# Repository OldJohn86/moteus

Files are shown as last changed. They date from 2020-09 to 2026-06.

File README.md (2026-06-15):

# moteus brushless servo #

This contains full designs for the moteus brushless servo actuator,
including firmware and PCBs.

**WARNING**: This is not just a software project.  It includes designs
for moderately high power electronics.  It has not yet burned down my
(or anyone's that I know of) house, but there are no guarantees.

# Specifications #

| Name | r4.11 | c1 | n1 | x1 |
|---|---|---|---|---|
| Voltage Input | 10-44V | 10-51V | 10-54V | 10-54V |
| Peak Electrical Power  | 900W @ 30V | 250W @ 28V | 2kW @ 36V | 1.3kW @ 36V |
| Mass | 14.2g | 8.9g | 14.6g | 23.8g |
| Control Rate | 15-30kHz | - | - | - |
| PWM Switching Rate | 15-60kHz | - | - | - |
| CPU | STM32G4 | - | - | - |
| Uncooled phase current | 12A | 5A | 9A | 25A |
| Cooled phase current | 32A | 14A | 26A | 62A |
| Peak phase current | 100A | 20A | 100A | 120A |
| Communications | 5Mbps CAN-FD | - | - | - |
| Dimensions | 46x53mm | 38x38x9mm  | 46x46x8mm | 56x56x10mm  |

Assembled and tested boards can be purchased at: https://mjbots.com

# Directory structure #

* hw/ - hardware (mechanical and electrical designs)
  * controller/ - PCB design for moteus-r4.11
  * c1/ - PCB design for moteus-c1
  * n1/ - PCB design for moteus-n1
  * x1/ - PCB design for moteus-x1
* fw/ - firmware for brushless controller
* lib/ - client side software
* utils/ - diagnostic tools
* tools/ - bazel build configure
* docs/ - documentation

# Documentation #

* [Quick Start](https://mjbots.github.io/moteus/quick-start)
* [All Documentation](https://mjbots.github.io/moteus/)
* [Discord](https://discord.gg/W4hUpBb)

# Misc #

 * 

# How to support moteus development #

The easiest way to support development the moteus hardware and firmware is as follows:

1) Buy things from https://mjbots.com
2) Build awesome machines!

That's it!  If for some reason you want to go above and beyond, you can sponsor mjbots through github: https://github.com/sponsors/mjbots

# License #

All files contained in this repository, unless otherwise noted, are
available under an Apache 2.0 License:
https://www.apache.org/licenses/LICENSE-2.0

# Trademark #

mjbots Robotic Systems LLC owns and protects the "mjbots" and "moteus" trademarks in many jurisdictions.

If you want to use these names in your project or product, please read the [Trademark Policy](https://mjbots.com/trademark-policy)

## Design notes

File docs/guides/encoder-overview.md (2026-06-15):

# Encoder Overview

This section describes the various ways moteus can be configured to use encoders to sense the rotor, output, or auxiliary devices.  If you intend to only use the onboard on-axis magnetic encoder, you can skip this section.

## Introduction

moteus uses encoders to properly control a motor. Encoders provide the feedback needed to know where the motor is and how fast it's moving. Understanding which encoder(s) to use and how to configure them is one of the key decisions you need to make when designing a system, as for many applications encoder selection is the primary determinant of performance parameters like maximum stiffness, control stability and whether homing will be necessary.

Moteus uses encoders for two distinct purposes. First, it needs **commutation** feedback - the electrical relationship between the motor's stator and rotor to apply torque correctly. Second, it needs **output** feedback - the position and velocity of your output shaft to follow commanded trajectories. A single encoder can serve both purposes, or you can use separate encoders for each.

The good news is that moteus comes with an onboard AS5047P or MA600 magnetic encoder that works out of the box for many applications. This encoder mounts on-axis with the motor. For many use cases, especially those without gear reductions, this is all you need. However, if you're using hall sensors, need higher resolution, or have a gear reducer that you want to measure the output of a reducer or other auxiliary devices, you'll want to add other encoders.

In this guide, we'll cover a few common variants and leave the rest for [the detailed encoder reference](../reference/encoders.md).

## Common Configurations

Here are the most common encoder configurations you'll encounter:

**Default configuration (onboard encoder only):** The AS5047P or MA600 onboard encoder serves as both commutation and output sensor. This works well for many applications, especially those without a reducer installed or with a reducer where either the absolute position of the output is not required or a homing step is permitted.

**Adding hall sensors:** Hall effect sensors provide robust commutation feedback and are useful in high-vibration environments or when cost is a primary concern.  When used as the only encoder, the resulting system will have poor low-velocity and position tracking performance.

**Dual encoder setups:** Using one encoder for commutation (typically the onboard or hall sensors) and a separate high-resolution encoder for output position provides the best performance for precision applications.

These two options are described in separate guides below:

- [Motor with Hall Effects](hall-effects.md) - Adding hall sensors for commutation
- [Dual Encoders](dual-encoders.md) - Using separate encoders for commutation and output

Once again, for detailed information about encoder configuration parameters, see the [Detailed Encoder Reference](../reference/encoders.md).

## Next Steps

Once the encoder has been configured, then you are ready to move on to the [motor calibration procedure](calibration.md).

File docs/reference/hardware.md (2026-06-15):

# Hardware Specifications

## CAD and Models

| Name | 2D CAD | 3D Model |
|---|---|---|
| moteus-c1 |[2D CAD](https://github.com/mjbots/moteus/blob/0.1-20240430/hw/c1/r1.2/20240305-moteus-c1-r1_2.pdf) | [STEP](https://github.com/mjbots/moteus/blob/0.1-20240430/hw/c1/r1.2/20240305-moteus-c1-r1_2.step) |
| moteus-r4 |[2D CAD](https://github.com/mjbots/moteus/blob/main/hw/controller/r4.5/20210124-moteus-controller-r45-mechanical.pdf) | [STEP](https://github.com/mjbots/moteus/blob/main/hw/controller/r4.5/20210124-moteus-controller-r45-mechanical.step) |
| moteus-x1 | [2D CAD](https://drive.google.com/file/d/1R7wuc7vk1khD5ZvDWPy54Bx4PgHYiUCu/view) | [STEP](https://drive.google.com/file/d/19tJa4gzy0ZBWYYsaJA-Du0PgzoDWizjL/view?usp=sharing) |
| moteus-n1 | [2D CAD](https://drive.google.com/file/d/1Ic65vT8BSeTtqz6uqd8C7l68aOMy3bMz/view?usp=share_link) | [STEP](https://drive.google.com/file/d/1wxX5G6kX6M6YZGGSceiXTOUZycxRaSIE/view?usp=share_link) |

## Electrical Limits

| Name | Min Voltage | Nominal | Abs Max Voltage | Peak Output | 3V Aux |  5V Aux | 12V Aux |
|---|---|---|---|---|---|---|---|
| moteus-c1 | 10V | 24V | 51V (<= 12S) | 20A | 50mA | 100mA | N/A |
| moteus-r4 | 10V | 24V | 44V (<= 10S) | 100A | 100mA | N/A | N/A |
| moteus-x1 | 10V | 24V | 54V (<= 12S) | 120A | 100mA | 200mA | 150mA |
| moteus-n1 | 10V | 24V | 54V (<= 12S) | 100A | 100mA | 200mA | N/A |

## Power Limits

The allowable maximum power for each moteus controller depends upon
the input voltage and PWM switching frequency.  The below table gives
the maximum allowable power at `servo.pwm_rate_hz=30000`.

| Name | Peak power | | High input power |
|---|---|---|---|
| moteus-r4  | <= 30V 900W  | linear derated | >= 38V 400W |
| moteus-c1  | <= 28V 250W  | linear derated | >= 41V 150W |
| moteus-n1  | <= 36V 2000W | linear derated | >= 44V 1000W |

For other values of `servo.pwm_rate_hz`, the allowable maximum power
changes linearly with the PWM rate, so that at 15000, the maximum
power is half of that in the above table and at 60000 it is double
that.  Note however, that efficiency of the controller goes down
significantly at higher PWM rates.

The current power limit is reported in `servo_stats.max_power_W`.  The
controller will attempt to limit output phase current so as to stay
within this reported power limit in either direction, i.e. applying
power or regenerating energy.

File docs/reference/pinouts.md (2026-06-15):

# Pinouts

## moteus-c1



## moteus-r4



## moteus-x1



## moteus-n1



## Additional Information

### CAN Termination

CAN connections should be terminated by a 120 ohm resistor at both
ends of a bus.  Some mjbots products have built in termination
resistors, such as the pi3hat.  The mjcanfd-usb-1x and fdcanusb have a
software configurable termination resistor that is by default on.
moteus controllers have no termination resistors.  For very short
runs, the system will work terminated only on one side.  However, when
runs become longer than 0.5m, you will likely need to terminate both
ends.  This can be done by crimping a 120 ohm resistor into a JST PH3
connector and connecting it to the open data connector or by
purchasing a [CAN terminator](https://mjbots.com/products/jst-ph3-can-fd-terminator).

### Recommended Mating Hardware

| Connector | Mate P/N | Terminal P/N | Pre-crimped Wire |
|---|---|---|---|
| JST PH-3  | [PHR-3](https://mjbots.com/products/phr-3)  | [SPH-002T-P0.5L](https://mjbots.com/products/jst-ph-terminal) | [10cm, 30cm, 50cm PH3](https://mjbots.com/products/jst-ph3-cable) |
| JST GH-6  | [GHR-06V-S](https://mjbots.com/products/jst-gh6-housing) | [SSHL-002T-P0.2](https://www.digikey.com/en/products/detail/jst-sales-america-inc/SSHL-002T-P0-2/807828) | [28 AWG 20cm](https://mjbots.com/products/jst-gh-wire) |
| JST GH-7  | [GHR-07V-S](https://mjbots.com/products/jst-gh7-housing) | [SSHL-002T-P0.2](https://www.digikey.com/en/products/detail/jst-sales-america-inc/SSHL-002T-P0-2/807828) | [28 AWG 20cm](https://mjbots.com/products/jst-gh-wire) |
| JST GH-8  | [GHR-08V-S](https://mjbots.com/products/jst-gh8-housing) | [SSHL-002T-P0.2](https://www.digikey.com/en/products/detail/jst-sales-america-inc/SSHL-002T-P0-2/807828) | [28 AWG 20cm](https://mjbots.com/products/jst-gh-wire) |
| JST ZH-4  | [ZHR-4](https://www.digikey.com/en/products/detail/jst-sales-america-inc/ZHR-4/608643) | [SZH-002T-P0.5](https://www.digikey.com/en/products/detail/jst-sales-america-inc/SZH-002T-P0-5/527363) | |
| JST ZH-6  | [ZHR-6](https://www.digikey.com/en/products/detail/jst-sales-america-inc/ZHR-6/527361) | [SZH-002T-P0.5](https://www.digikey.com/en/products/detail/jst-sales-america-inc/SZH-002T-P0-5/527363) | [stm32 programmer](https://mjbots.com/products/stm32-programmer) |
| AMass XT30 | [XT30U-F](https://mjbots.com/products/xt30u-f) | | |

### Recommended Low Cost Manual Crimp Tools

- **JST PH**: [TU-190-08](https://www.amazon.com/TU-190-08-Terminals-Tool-Crimping-0-08-0-5sq-mm/dp/B01M25OLZY)
- **JST ZH**: [PEBA 1020M](https://www.amazon.com/PEBA-Ratcheting-Connectors-Crimping-terminals/dp/B0D7PKLBZT)
- **JST GH**: [PEBA 1020M](https://www.amazon.com/PEBA-Ratcheting-Connectors-Crimping-terminals/dp/B0D7PKLBZT)

### moteus-r4 - Pico-SPOX 6 ENC

The ENC/AUX1 connector on moteus-r4 are intended to be populated with
a Molex Pico-SPOX 6 connector PN 0874380643, or as an alternate, TE
5-1775444-6.

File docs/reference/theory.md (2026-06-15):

# Theory of Operation

The moteus controller is intended to drive 3 phase brushless motors
using field oriented control.  It has an integrated magnetic encoder
for sensing the rotor position, 3 half-H bridges for switching power
to each of the three phases, and current sense capability on each of
the three phases.

The primary control mode, labeled as "position" mode in the rest of
this document is a two stage cascaded controller, with both running at
the switching frequency (by default 30kHz).

The outermost stage is an optional limited acceleration and velocity
trajectory planner.  Within that is an integrated position/velocity
PID controller with optional feedforward torque.  The output of that
loop is a desired torque/current for the Q phase of the FOC
controller.

The inner stage is a current mode PI controller.  Its output is the
desired voltage value for the Q phase.  Then the magnetic encoder is
used to map the D/Q phase voltage values to the 3 phases of the motor.

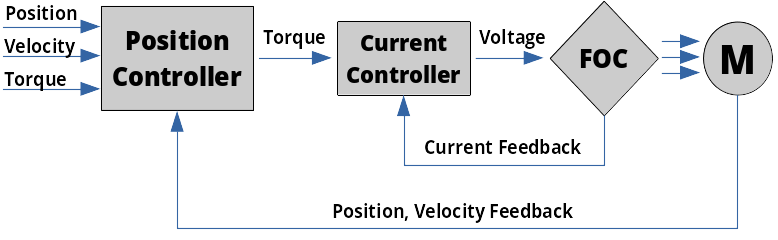
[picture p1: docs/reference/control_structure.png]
Control Structure


More precisely, the "Position Controller" implements the following
control law:

```
acceleration = trajectory_follower(command_position, command_velocity)
control_velocity = command_velocity OR control_velocity + acceleration * dt OR 0.0
control_position = command_position OR control_position + control_velocity * dt
position_error = control_position - feedback_position
velocity_error = control_velocity - feedback_velocity
position_integrator = limit(position_integrator + ki * position_error * dt, ilimit)
torque = position_integrator +
         kp * kp_scale * position_error +
         kd * kd_scale * velocity_error +
         command_torque
```

And the "Current Controller" implements the following control law:

```
current_error = command_current - feedback_current
current_integrator = limit(current_integrator + ki * current_error, ilimit)
voltage = current_integrator + kp * current_error
```

Since PID scaling for the position mode loop can be adjusted on a
cycle-by-cycle basis with the `kp_scale` and `kd_scale` terms, this
allows you to operate the controller with full
position/velocity/torque control, or velocity/torque, or just torque,
or any combination seamlessly throughout the control cycle.

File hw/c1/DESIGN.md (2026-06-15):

moteus-c1 is a small form factor controller with the flexibility of
the moteus-n1, but designed for lower power and current applications.

# r1.1 fixes #

 * U2 3.3V regulator has enable pin undriven
 * Switched U2 to part TLV70233PDBVR which is SOT23-5 and has better
   thermal properties
 * removed gate drive resistors and discharge diodes
 * moved C7 away from AUX1/AUX2 pins
 * switch can terminator (R6) to 0603 and move further away from power
   pad
 * rev silk version to r1.1
 * version divider pulled low
 * revved TVS to the 48V version, so 3V lower than before... that will
   make the rated max voltage be 51V instead of 54V
 * added unpopulated resistor and capacitor between power ground and a
   mounting hole

# TODO #

# r1.0 ERRATA #
 * C7 blocks access to the through hole pins (they barely fit, but
   could use a bit more margin)
 * can termination resistor pad is too close to power pin of XT30
 * high side FET trace to DRV is too small compared to gate drive
   trace and should be swapped around to be a pair with gate drive
 * board version divider should never be floating, needs to be
   pulled low for next rev
 * remove gate drive resistors and reverse diodes
 * 3.3V regulator should be the SOT-23 package that has better
   thermals
 * need to fully lay out what the family pullup/pulldowns are so
   that I can be sure they can all be distinguished

r1.1 MAYBE
 * possible remove all the gate drive resistors and protection diodes?
 * maybe lower max voltage to 51V and drop the TVS diode by one step

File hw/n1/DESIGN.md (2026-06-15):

moteus-n1 is intended as a higher power/voltage, more flexible, yet
smaller in footprint version of the moteus brushless controller.

# Features #

 * 51V max voltage (vs 44V for moteus)
 * More flexible aux1/aux2 connectors
   * both JST GH (aux1 is 8 pin, aux2 is 7 pin)
   * 200mA of 5V between both connectors
   * 200mA of 3V between both connectors
   * aux1 now has two pins that can be used even if onboard encoder is used
   * SPI on both connectors
   * UART on both connectors
   * ADC on both connectors
   * Sine/cosine on both connectors
   * Hardware quadrature (higher count rates)
 * RS422 transceiver and connector (consumes the two spare pins on AUX1)
 * No connectors required on bottom of board for smaller footprint
 * Optional solder pads for power in for higher current capability
 * Variants
   * optional power/CAN connectors on bottom for daisy chaining
 * CAN transceiver with 58V bus fault voltage
 * 46x46mm

# Pin Allocation #

 * PA0  - MOTOR 1       (fast ADC1/2)
 * PA1  - MOTOR 2       (fast ADC1/2)
 * PA2  - MOTOR 3       (fast ADC1)
 * PA3  - CURRENT       (fast ADC1)
 * PA4  - DEBUG_DAC
 * PA5  - AUX1_A
 * PA6  - CURRENT       (fast ADC2)
 * PA7  - AUX1_C
 * PA8  - TSENSE2       (fast ADC5)
 * PA9  - VSENSE        (fast ADC5)
 * PA10 - AUX2_A
 * PA11 - AUX2_B
 * PA12 - AUX2_I2C_PULLUP
 * PA13 - SWDIO
 * PA14 - SWCLK
 * PA15 - AUX1_D
 * PB0  - DRV8353 CS
 * PB1  - CURRENT        (fast ADC3)
 * PB2  - AS5047P CS     (ADC2)
 * PB3  - AUX1_E
 * PB4  - AUX1_B
 * PB5  - FDCAN2_RX
 * PB6  - FDCAN2_TX
 * PB7  - AUX2_C
 * PB8  - AUX1_I2C_PULLUP
 * PB9  - AUX1_E
 * PB10 - RS422_RE
 * PB11 - RS422_DE      (ADC1/2)
 * PB12 - TSENSE1      (fast ADC4)
 * PB13 - MOTOR_FAULT  (fast ADC3)
 * PB14 - AUX1_A       (fast ADC1/4)
 * PB15 - LED1         (fast ADC4)
 * PC4  - AUX2_B       (fast ADC2)
 * PC6  - LED2
 * PC10 - DRV8323 SCK
 * PC11 - DRV8323 MISO
 * PC13 - DRV8323 MOSI
 * PC14 - MOTOR_ENABLE
 * PC15 - MOTOR_HIZ
 * PF0 - AUX2_A
 * PF1 - AUX2_D

# Pins Required #

     * LEDs - 2
     * as5047 CS - 1
     * drv8353 CS - 1
     * 2x temp sense - 2
     * debug uart - 2
     * swd - 2
     * DAC debug?
     * voltage sense - 1
     * aux ADC - 2
     * primary aux - 1
     * CAN - 2
     * current sense - 3
       * needs to be "fast" ADC channels
     * aux fixed conn - 2
     * primary fixed conn - 4 (SPI shared with as5047)
     * drv8353 SPI - 3
     * gate PWM - 3

# Connectors #

## Aux 1 ##

 * notional pins (8  pins)
  * 5V
  * 3.3v
  * A: SPI1_SCK  / ADC1 / TIM2_CH1                             - PA5 / PB14
  * B: SPI1_MISO /      / TIM3_CH1 /          / USART2_RX / 5V - PB4
  * C: SPI1_MOSI / ADC2 / TIM3_CH2                             - PA7
  * D:           /      / TIM2_CH1 / I2C1_SCL / USART2_RX / 5V - PA15
  * E: SPI1_SCK  /      / TIM2_CH2 / I2C1_SDA / USART2_TX / 5V - PB3 / PB9
  * gnd

## Aux 2 ##

 * 3V and 5V power
 * I2C
 * quadrature
 * index
 * uart
 * SPI
 * PA14/PA15 have I2C1 and USART2 and TIM8_CH1/2
 * PB8/PB9 have I2C1 and USART3 and TIM4_CH3/4
 * TIM1/2 options: PA0/1/2/3/5/6/7/12/15
                   PB2/3/4/5/6/7/8/9/14/15
 * notional pins (7 pins)
   * 5V
   * 3V
   * A: SPI2 SCK  /           /          / ADC2 /           - PF1
   * B: SPI2 MISO / USART1_RX / I2C2_SDA / ADC1             - PA10 / PF0
   * C: SPI2 MOSI / USART1_TX / I2C2_SCL / ADC2 / TIM4_CH1  - PA11 / PC4
   * D:             USART1_RX /                 / TIM4_CH2  - PB7
   * gnd

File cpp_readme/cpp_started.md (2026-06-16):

# Moteus 使用笔记

## macOS 启动 tview

```bash
python3 -m moteus_gui.tview --devices=1 --fdcanusb /dev/cu.usbmodemAAC8D32F1
```

> `AAC8D32F1` 是设备序列号，按实际替换。

---

## Moteus 项目总结

### 是什么

mjbots Robotic Systems 开发的全开源无刷伺服控制器系统（Apache 2.0），从 PCB 设计到固件到客户端库全部开源，同时在 mjbots.com 销售成品板。目标场景是高性能机器人关节。

### 架构三层

```
[硬件 PCB]  →  [STM32G4 固件]  →  [客户端库: Python / C++ / Rust]
               baremetal, no RTOS     同一套寄存器协议
```

- **固件** (`fw/`): 纯裸机 C++，mbed-OS 仅作 HAL。主循环 poll 毫秒定时器；实时控制在硬件 ISR 中完成，无调度器开销。启动链路：`Fdcan → FDCanMicroServer → MultiTransportDatagramServer → MicroServer → MoteusController → BldcServo`。
- **控制环** (`bldc_servo_control.h`, 1815 行): 标准 FOC——三相电流 ADC → Clarke → Park → DQ 电流 PI → 逆 Park → SVM。全部放在 CCM SRAM（零等待状态）；sin/cos 由 STM32G4 的 CORDIC 硬件协处理器计算。
- **通信协议**: 自定义 multiplex 寄存器映射（v5），寄存器地址 uint16，数值精度可按需选 INT8/INT16/F32——每帧省字节即省 CAN-FD 带宽。仲裁 ID 编码源/目标 node ID（1–126），同一 CAN 总线可同时跑控制命令 + 文本诊断 tunnel。

### 硬件型号

| | r4.11 | c1 | n1 | x1 |
|---|---|---|---|---|
| 输入电压 | 10–44V | 10–51V | 10–54V | 10–54V |
| 峰值功率 | 900W | 250W | 2kW | 1.3kW |
| 峰值相电流 | 100A | 20A | 100A | 120A |
| 重量 | 14.2g | 8.9g | 14.6g | 23.8g |
| PWM 频率 | 30–60kHz | 15kHz | 30kHz | 30kHz |

同一份固件二进制，运行时 `DetectMoteusFamily()` 自动适配板型差异（电流采样电阻、电压限制、TDC 补偿等）。

### 客户端生态

- **Python** (`lib/python/moteus/`): asyncio 原生，`Controller` 封装所有模式。`QueryResolution`/`PositionResolution` 描述符可按调用控制寄存器精度。Transport: fdcanusb（USB CDC）、python-can（SocketCAN 等）。
- **C++** (`lib/cpp/mjbots/moteus/`): 纯头文件，支持阻塞和回调异步两种 API。`moteus_protocol.h` 可单独嵌入使用。
- **Rust** (`lib/rust/`): 拆为 `moteus-protocol`（no_std，可嵌入）+ `moteus`（std，transport）。`BlockingController::new(id)` 自动发现 transport；支持 fdcanusb、SocketCAN、TTL UART。

### 值得关注的技术点

1. **Watchdog 安全模型**: `kPositionTimeout` 是独立的受控降级状态，而非简单报错——必须主动发 stop 才能退出，防止断连后失控。
2. **256 点齿槽力矩补偿表**: 每个电气周期 256 采样的前馈表，由标定工具生成存入 flash，可显著降低低速转矩脉动。
3. **传输复用**: 同一根 CAN-FD 总线既跑电机指令，也跑 multiplex tunnel（虚拟串口），`tview.py` 通过 tunnel 读取实时遥测和文本控制台，无需额外调试接口。
4. **1.0.0 首次语义化版本**: 2026-05-28 发布，固件 + Python + C++ 同步打标，寄存器映射版本（v5）存入固件，客户端可检测不匹配。

### 构建体系

Bazel 唯一构建工具，必须用仓库自带的 `tools/bazel` 包装器（版本锁定）。CMake 仅作 C++ 客户端库的兼容 shim。CI 跑两趟测试：普通 host 构建 + UBSan 构建，再加一次 firmware 交叉编译。

---

## 构建方式 & 环境要求

### macOS 限制

`tools/bazel` 包装脚本写死下载 Linux x86_64 的 Bazel 二进制，**macOS 上无法直接使用**。官方支持平台是 Linux x86_64。

### Linux 环境要求

| 项目 | 要求 |
|---|---|
| OS | Ubuntu（推荐 22.04/24.04） |
| Python | **3.7–3.x**（`requires-python = ">=3.7, <4"`），建议用系统 Python 3.12 配合 apt 包 |
| 编译器 | Bazel 自动下载 LLVM 20.1.8，无需手动装 GCC/Clang |
| Bazel | 由 `tools/bazel` 自动下载 7.4.1，**不要用系统 bazel** |
| curl | 供 `tools/bazel` 下载 Bazel 本体 |

安装 Ubuntu 系统包：

```bash
sudo apt update
sudo apt install -y python3-build python3-can python3-serial python3-setuptools \
    python3-pyelftools python3-qtpy python3-wheel python3-importlib-metadata \
    python3-scipy python3-usb mypy nodejs
```

C++ 测试额外需要：

```bash
wget http://security.ubuntu.com/ubuntu/pool/universe/n/ncurses/libtinfo5_6.3-2ubuntu0.1_amd64.deb
sudo apt install -y ./libtinfo5_6.3-2ubuntu0.1_amd64.deb
```

避免 Python 版本冲突：

```bash
sudo mv /usr/local/bin/python3 /usr/local/bin/python3.bak
```

### 三类构建目标

```bash
# 编译固件（交叉编译 STM32G4）
tools/bazel build --config=target //:target

# 运行 host 单元测试（快速，默认 small size）
tools/bazel test --config=host //:host

# 完整测试套件（含仿真回归 + UBSan）
./travis-ci.sh
```

单独跑某个测试：

```bash
tools/bazel test --config=host //fw:test         # 固件 C++ 单元测试
tools/bazel test --config=host //utils:test      # 工具测试
tools/bazel test --config=host //lib/python:host # Python 库测试
tools/bazel test //lib/rust:host                 # Rust 库测试
```

### macOS 上的替代方案

- **直接用 Python 库**（无需构建）：`pip install moteus`，或直接运行 `utils/moteus_tool.py` / `utils/tview.py`
- **构建固件**：需在 Linux 机器或 Docker 容器内进行

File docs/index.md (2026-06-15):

# moteus Brushless Servo Documentation

Welcome to the documentation site for the moteus brushless motor controller.

## What is moteus?

moteus controllers are high-performance modular brushless motor controllers with integrated on-axis magnetic encoders, designed for robotics applications. They feature:

- **Field Oriented Control (FOC)** for 3-phase brushless motors
- **Integrated magnetic encoder** for precise position sensing
- **High-speed CAN-FD communication** at 5Mbps
- **Multiple control modes**: Position, velocity, and torque control with acceleration and velocity limited trajectories
- **Fast control loops** running at 15-30kHz

## Hardware Variants

| Name | Voltage Input | Peak Power | Mass  | Dimensions |
|---|---|---|---|---|
| r4.11  | 10-44V | 900W @ 30V | 14.2g | 46x53mm |
| c1 | 10-51V | 250W @ 28V | 8.9g  | 38x38x9mm |
| n1 | 10-54V | 2kW @ 36V | 14.6g | 46x46x8mm |
| x1 | 10-54V | 1.3kW @ 36V | 23.8g | 56x56x10mm |

Assembled and tested boards can be purchased at [mjbots.com](https://mjbots.com)

## Documentation

- [Quick Start](quick-start.md)
- [Using Moteus](guides/mechanical-setup.md)
- [Integration](integration/python.md)
- [Troubleshooting](troubleshooting/calibration.md)
- [Reference](reference/pinouts.md)

## Community & Support

- [Discord Community](https://discord.gg/W4hUpBb)
- [GitHub Repository](https://github.com/mjbots/moteus)
- [Purchase Hardware](https://mjbots.com)

## License

All files in this repository are available under the [Apache 2.0 License](https://www.apache.org/licenses/LICENSE-2.0).

!!! note "Trademark Notice"
    mjbots Robotic Systems LLC owns and protects the "mjbots" and "moteus" trademarks. Please read the [Trademark Policy](https://mjbots.com/trademark-policy) if you want to use these names in your project.

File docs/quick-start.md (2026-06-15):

# Quick Start Guide

New to moteus?  Work through these sections in order.  The first set
is if you have a bare board, the second is if you are starting from a
developer kit.

## Setup Overview for Bare Boards

If you have a bare moteus board and a motor, these steps are for you.

1. **[Mechanical Setup](guides/mechanical-setup.md)** - Mount the encoder magnet and controller
2. **[Electrical Setup](guides/electrical-setup.md)** - Connect phase wires and power
3. **[Software Installation](guides/software-installation.md)** - Install and run tview
4. **[Configuration](guides/configuration.md)** - Set essential parameters
5. **[Encoder Overview](guides/encoder-overview.md)** - Understand encoder options (if using external encoders)
6. **[Calibration](guides/calibration.md)** - Calibrate the controller for your motor
7. **[PID Tuning](guides/pid-tuning.md)** - Tune the position control constants
8. **[Control Modes](guides/control-modes.md)** - Learn how to control the motor

## Developer Kit Users

If you're starting from a developer kit, the motor is already mounted,
configured, calibrated and tuned. Your job is easier, yay!  Just follow these steps:

1. **[Software Installation](guides/software-installation.md)** - Install tview
2. **[Control Modes](guides/control-modes.md)** - Start controlling your motor

## Need Help?

- **[Troubleshooting](troubleshooting/calibration.md)** - Common issues and solutions
- **[Discord Community](https://discord.gg/W4hUpBb)** - Get help from the community
- **[GitHub Issues](https://github.com/mjbots/moteus/issues)** - Report bugs or request features
- **[info@mjbots.com](mailto:info@mjbots.com)** - Email support

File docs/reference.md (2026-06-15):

# Reference Documentation

This page has been reorganized. Please use the navigation menu or the links below to find the content you're looking for.

## Quick Links

### Theory and Operation

**[Theory of Operation](https://mjbots.github.io/moteus/reference/theory/)** - Controller architecture and control laws

**[Usage Modes / Control Modes](https://mjbots.github.io/moteus/guides/control-modes/)** - Position, velocity, and torque control modes

### Configuration

**[Initial Parameters / Configuration](https://mjbots.github.io/moteus/guides/configuration/)** - Getting started with configuration

**[Encoder Configuration](https://mjbots.github.io/moteus/guides/encoder-overview/)** - Encoder setup and configuration

**[Auxiliary Port](https://mjbots.github.io/moteus/reference/encoders/#auxiliary-port)** - Auxiliary connector configuration and pinouts

**[AUX1/ENC Pins](https://mjbots.github.io/moteus/reference/encoders/#r411-pins-aux1enc)** - r4.11 AUX1/ENC connector pinout

**[AUX2/ABS Pins](https://mjbots.github.io/moteus/reference/encoders/#r411-pins-aux2abs)** - r4.11 AUX2/ABS connector pinout

**[AUX GPIO Output Control](https://mjbots.github.io/moteus/protocol/diagnostic/#aux1-out-set-gpio-output-values)** - Setting GPIO outputs via diagnostic commands

**[AUX UART Mode](https://mjbots.github.io/moteus/reference/encoders/#uart)** - Configuring UART on auxiliary ports

**[Pin Capabilities](https://mjbots.github.io/moteus/reference/encoders/#io-pin-capabilities)** - Available pin modes and configurations

### Configuration Parameters

**[id.id](https://mjbots.github.io/moteus/reference/configuration/#idid)** - Device ID configuration

**[servo.default_timeout_s](https://mjbots.github.io/moteus/reference/configuration/#servodefault_timeout_s)** - Command timeout configuration

**[servo.flux_brake_margin_voltage](https://mjbots.github.io/moteus/reference/configuration/#servoflux_brake_margin_voltage)** - Flux braking voltage threshold

**[servo.max_power_W](https://mjbots.github.io/moteus/reference/configuration/#servomax_power_w)** - Maximum power limit

**[servo.pid_position](https://mjbots.github.io/moteus/reference/configuration/#servopid_position)** - Position PID controller parameters

**[servopos.position_min](https://mjbots.github.io/moteus/reference/configuration/#servoposposition_min)** - Minimum position limit

**[motor_position.output.offset/sign](https://mjbots.github.io/moteus/reference/configuration/#motor_positionoutputoffsetsign)** - Output encoder offset and sign

**[motor_position.rotor_to_output_ratio](https://mjbots.github.io/moteus/reference/configuration/#motor_positionrotor_to_output_ratio)** - Gear reduction ratio

**[Configuration Commands](https://mjbots.github.io/moteus/protocol/diagnostic/#conf-configuration)** - Reading and writing configuration via console

### Register Reference

**[0x000 - Mode](https://mjbots.github.io/moteus/protocol/registers/#0x000-mode)** - Operational mode register

**[0x00f - Fault Code](https://mjbots.github.io/moteus/protocol/registers/#0x00f-fault-code)** - Fault status register

**[0x014/0x15/0x16 - Voltage Phase A/B/C](https://mjbots.github.io/moteus/protocol/registers/#0x014-0x15-0x16-voltage-phase-a-b-c)** - Phase voltage control registers

**[0x020 - Position Command](https://mjbots.github.io/moteus/protocol/registers/#0x020-position-command)** - Position setpoint register

**[0x021 - Velocity Command](https://mjbots.github.io/moteus/protocol/registers/#0x021-velocity-command)** - Velocity setpoint register

**[0x023 - Kp Scale](https://mjbots.github.io/moteus/protocol/registers/#0x023-kp-scale)** - Proportional gain scaling

**[0x025 - Maximum Torque](https://mjbots.github.io/moteus/protocol/registers/#0x025-maximum-torque)** - Torque limit register

**[0x028 - Velocity Limit](https://mjbots.github.io/moteus/protocol/registers/#0x028-velocity-limit)** - Trajectory velocity limit

**[0x058 - Encoder Validity](https://mjbots.github.io/moteus/protocol/registers/#0x058-encoder-validity)** - Encoder status bitfield

**[0x05c - Aux1 GPIO Command](https://mjbots.github.io/moteus/protocol/registers/#0x05c-aux1-gpio-command)** - GPIO output control register

**[0x070 - Millisecond Counter](https://mjbots.github.io/moteus/protocol/registers/#0x070-millisecond-counter)** - System timestamp register

**[0x131 - Set Output Exact](https://mjbots.github.io/moteus/protocol/registers/#0x131-set-output-exact)** - Force absolute position register

**[0x150-0x153 - UUID](https://mjbots.github.io/moteus/protocol/registers/#0x150-0x153-uuid)** - Device UUID registers

**[0x154-0x157 - UUID Mask](https://mjbots.github.io/moteus/protocol/registers/#0x154-0x157-uuid-mask)** - UUID filtering registers

**[Register Mappings](https://mjbots.github.io/moteus/protocol/registers/#mappings)** - Data type encodings and scaling

**[Register List](https://mjbots.github.io/moteus/protocol/registers/#registers)** - Complete register documentation

### CAN Protocol

**[CAN Format](https://mjbots.github.io/moteus/protocol/can/#can-format)** - CAN-FD frame structure

**[Write Registers](https://mjbots.github.io/moteus/protocol/can/#write-registers)** - Register write subframe format

**[CAN Protocol Example](https://mjbots.github.io/moteus/protocol/can/#example)** - Sample CAN frame breakdown

**[Sending Multiple Commands](https://mjbots.github.io/moteus/reference/client-tools/#sending-multiple-commands-at-once)** - Batching commands in tview

**[Communicating with Specific Device](https://mjbots.github.io/moteus/reference/client-tools/#communicating-with-a-specific-device)** - Targeting devices by ID

**[CAN Bit Timings](https://mjbots.github.io/moteus/platforms/socketcan/#bit-timings)** - socketcan bitrate configuration

**[Clock-Specific Bit Timings](https://mjbots.github.io/moteus/platforms/socketcan/#bit-timings)** - 40MHz and 80MHz configurations

### Diagnostic Commands

**[Diagnostic Protocol](https://mjbots.github.io/moteus/protocol/diagnostic/)** - Console command reference

**[d pwm](https://mjbots.github.io/moteus/protocol/diagnostic/#d-pwm)** - Raw PWM control command

**[d nearest](https://mjbots.github.io/moteus/protocol/diagnostic/#d-nearest)** - Set output nearest command

**[d cfg-set-output](https://mjbots.github.io/moteus/protocol/diagnostic/#d-cfg-set-output)** - Configure output encoder

### Hardware Reference

**[Pinouts](https://mjbots.github.io/moteus/reference/pinouts/)** - Connector pinouts for all board variants

**[Debug Port (JST ZH-6)](https://mjbots.github.io/moteus/reference/pinouts/)** - SWD debug connector

**[n1/c1 AUX2 (JST GH-7)](https://mjbots.github.io/moteus/reference/pinouts/)** - n1 and c1 auxiliary port connector

**[r4 ABS (JST ZH-4)](https://mjbots.github.io/moteus/reference/pinouts/)** - r4 absolute encoder connector

**[r4 ENC (Pico-SPOX-6)](https://mjbots.github.io/moteus/reference/pinouts/)** - r4 incremental encoder connector

**[Hardware Specifications](https://mjbots.github.io/moteus/reference/hardware/)** - Electrical ratings and mechanical information

**[Application Limits](https://mjbots.github.io/moteus/reference/limits/)** - Position, velocity, and performance constraints

### Calibration and Tuning

**[Calibration](https://mjbots.github.io/moteus/guides/calibration/)** - Motor and encoder calibration procedures

**[PID Tuning](https://mjbots.github.io/moteus/guides/pid-tuning/)** - Controller tuning methodology

### Firmware and Tools

**[Flashing and Building Firmware](https://mjbots.github.io/moteus/reference/firmware/)** - Firmware compilation and installation

**[tview Usage](https://mjbots.github.io/moteus/reference/client-tools/#tview-usage)** - Command-line tool documentation

### Deployment

**[Deployment Considerations](https://mjbots.github.io/moteus/guides/electrical-setup/)** - Production design guidelines and safety considerations

### Additional Topics

**[Hall Effect Sensors](https://mjbots.github.io/moteus/reference/encoders/#hall-sensor)** - Using motors with hall effect sensors or configuring hall sensor pins

**[Position Mode](https://mjbots.github.io/moteus/guides/control-modes/#understanding-position-mode)** - Position control details

**[Torque Control](https://mjbots.github.io/moteus/guides/control-modes/#torque-control)** - Direct torque control mode

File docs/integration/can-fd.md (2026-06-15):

# CAN-FD

The python and C++ libraries are not required to command and monitor moteus, they just make it easier.  Any system capable of generating and receiving CAN-FD frames with the appropriate timing can be used.  Here are some hints to make that easier.

## Bit timing and basic communication

Moteus requires 1Mbps/5Mbps CAN-FD timing, a sample point of 0.666, and works best if the SJW and DSJW settings are as large as possible.

If communication is not working, it is recommended to attach a mjcanfd-usb-1x to the bus at the same time as your host and use it to capture frames.  Any serial application (or `cat` on Linux) can be used to read the output.  Since they start with the same timings as moteus, you can use that to identify if your frames are being received and being responded to.

## Decoding frames observed on the bus

There exists a tool in the moteus repository to decode CAN-FD frames sent to or from moteus that can be invaluable in diagnosing what you are sending and why moteus is or is not responding to it.  First, capture a hex formatted dump of the CAN-FD frame in question.  Then:

```
moteus$ ./utils/decode_can_frame.py 1100110F
11 - READ_REGISTERS - INT8 1 registers
  00 - Starting at reg 0x000(MODE)
11 - READ_REGISTERS - INT8 1 registers
  0f - Starting at reg 0x00f(FAULT)
```

and the corresponding response:

```
moteus$ ./utils/decode_can_frame.py 210000210F00
21 - REPLY - 0 1 registers
  00 - Starting at reg 0x000(MODE)
   00 - Reg 0x000(MODE) = 0(STOPPED)
21 - REPLY - 0 1 registers
  0f - Starting at reg 0x00f(FAULT)
   00 - Reg 0x00f(FAULT) = 0
```

## Generating appropriate command frames

The [CAN-FD reference](../protocol/can.md) and [register reference](../protocol/registers.md) contains the information necessary to generate and parse frames.  However, it can be a lot to digest.  You can use the [python library](../integration/python.md) to quickly get example frames that accomplish a given task.  First, create a python script that accomplishes what you want.  Then, in an interactive python REPL:

```
>>> print(c.make_position(position=1, velocity=2, query=True).data.hex())
01000a0e200000803f0000004011001f01130d
```

Where the arguments to `make_position` correspond to the action you want to accomplish.  You can verify the contents of this frame using `decode_can_frame.py`:

```
moteus$ ./utils/decode_can_frame.py 01000a0e200000803f0000004011001f01130d
01 - WRITE_REGISTERS - 0 1 registers
  00 - Starting at reg 0x000(MODE)
   0a - Reg 0x000(MODE) = 10(POSITION)
0e - WRITE_REGISTERS - 3 2 registers
  20 - Starting at reg 0x020(COMMAND_POSITION)
   0000803f - Reg 0x020(COMMAND_POSITION) = 1.0
   00000040 - Reg 0x021(COMMAND_VELOCITY) = 2.0
11 - READ_REGISTERS - INT8 1 registers
  00 - Starting at reg 0x000(MODE)
1f - READ_REGISTERS - F32 3 registers
  01 - Starting at reg 0x001(POSITION)
13 - READ_REGISTERS - INT8 3 registers
  0d - Starting at reg 0x00d(VOLTAGE)
```

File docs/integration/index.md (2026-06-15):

# Integration

Integrate moteus with your software and hardware.

- [Python Client](python.md) - Python client library
- [C++ Client](cpp.md) - C++ client library
- [Raw CAN-FD](can-fd.md) - Direct CAN-FD protocol access

## Host Platforms

- [Raspberry Pi](../platforms/raspberry-pi.md) - Using moteus with Raspberry Pi
- [Nvidia Jetson](../platforms/jetson.md) - Using moteus with Jetson boards
- [socketcan](../platforms/socketcan.md) - Linux SocketCAN setup
- [Arduino](../platforms/arduino.md) - Arduino integration

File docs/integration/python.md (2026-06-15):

# Python Client Library

moteus provides a python library that can be used to command and control moteus controllers using a supported CAN-FD adapter.

## Installation

To install, just use:

```
pip install moteus
```

Or add to your `requirements.txt` file, or via whatever mechanism your project uses.

## Basic Usage

There are two basic approaches to using the python library.  The first is the easiest, although does not provide optimal bus utilization if that is a design requirement.

First, construct one or more controller instances:

```python
import asyncio
import moteus

async def main():
    c1 = moteus.Controller(id=1)
    c2 = moteus.Controller(id=2)
    # ...

if __name__ == '__main__':
    asyncio.run(main())
```

Then, at regular intervals, send commands to each of the devices using the `set_` variant of each API.

```python
while True:
  c1_result = await c1.set_position(
      position=math.nan, velocity=1.0, accel_limit=0.5, query=True)
  c2_result = await c2.set_position(
      position=math.nan, velocity=0.5, accel_limit=0.25, query=True)

  c1_position = c1_result.values[moteus.Register.POSITION]
  c2_position = c2_result.values[moteus.Register.POSITION]

  print(c1_position, c2_position)

  await asyncio.sleep(0.01)
```

## `.cycle` based usage

If bus utilization or a high update rate is desired, an alternate API can be used to maximize performance.  In this API, the commands are constructed in advance using `make_` variants of commands, then submitted to the library in a group.

```python
import argparse
import asyncio
import moteus

async def main():
    parser = argparse.ArgumentParser()
    moteus.make_transport_args(parser)
    args = parser.parse_args()

    transport = moteus.get_singleton_transport(args)
    c1 = moteus.Controller(id=1, transport=transport)
    c2 = moteus.Controller(id=2, transport=transport)
    # ...

    while True:
        results = await transport.cycle([
           c1.make_position(position=math.nan, query=True)
           c2.make_position(position=math.nan, query=True),
           ])

        # Print the ID and position of all received responses.
        print(", ".join(
            f"{x.source} " +
            f"{x.values[moteus.Register.POSITION]}"
            for x in results))

        await asyncio.sleep(0.01)

if __name__ == '__main__':
    asyncio.run(main())
```

## Querying alternate registers

By default, only a limited set of registers are queried.  The full set of available registers can be found in the [register reference documentation](../protocol/registers.md).  The easiest way to query additional registers is to pass an alternate `QueryResolution` structure to the `Controller` constructor.

```python
qr = moteus.QueryResolution()
qr.power = moteus.F32
c = moteus.Controller(id=1, query_resolution=qr)
```

If the register you want is not available in the `QueryResolution` structure, it can be requested using the `_extra` method:

```python
qr = moteus.QueryResolution()
qr._extra = {
    moteus.Register.ENCODER_1_POSITION: moteus.F32,
    moteus.Register.ENCODER_1_VELOCITY: moteus.F32,
}
c = moteus.Controller(id=1, query_resolution=qr)
```

## API Reference

- [Python API Reference](../reference/python.md)

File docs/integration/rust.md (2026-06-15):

# Rust Client Library

moteus provides a Rust client library for commanding and controlling moteus controllers using a supported CAN-FD adapter. The library consists of two crates:

- **`moteus`** — High-level controller API with transport management
- **`moteus-protocol`** — Low-level `no_std` protocol encoding/decoding

## Installation

Add the moteus crate to your project:

```
cargo add moteus
```

Or add it directly to your `Cargo.toml`:

```toml
[dependencies]
moteus = "0.5"
```

For async support with tokio, enable the `tokio` feature:

```toml
[dependencies]
moteus = { version = "0.5", features = ["tokio"] }
```

For CLI argument parsing support, enable the `clap` feature:

```toml
[dependencies]
moteus = { version = "0.5", features = ["clap"] }
```

## Basic Usage — BlockingController

The simplest way to use moteus is with `BlockingController`, which provides synchronous, blocking communication:

```rust
use std::thread;
use std::time::Duration;
use moteus::{BlockingController, command::PositionCommand};

fn main() -> Result<(), moteus::Error> {
    // Auto-discovers transport on first use
    let mut ctrl = BlockingController::new(1);

    // Clear any faults
    ctrl.set_stop()?;

    // Send commands at regular intervals to prevent watchdog timeout
    loop {
        let result = ctrl.set_position(
            PositionCommand::new()
                .position(f32::NAN)
                .velocity(1.0)
                .accel_limit(0.5)
        )?;

        println!("Position: {} Velocity: {}", result.position, result.velocity);

        thread::sleep(Duration::from_millis(10));
    }
}
```

The `BlockingController` automatically discovers an available transport (fdcanusb, socketcan) on the first operation that needs it.

## Async Usage — AsyncController

For async applications, enable the `tokio` feature and use `AsyncController`:

```rust
use moteus::AsyncController;
use moteus::command::PositionCommand;

#[tokio::main]
async fn main() -> Result<(), moteus::Error> {
    // Auto-discovers transport on first use
    let mut ctrl = AsyncController::new(1);

    ctrl.set_stop().await?;

    loop {
        let result = ctrl.set_position(
            PositionCommand::new()
                .position(f32::NAN)
                .velocity(0.5)
        ).await?;

        println!("Position: {}", result.position);

        tokio::time::sleep(std::time::Duration::from_millis(10)).await;
    }
}
```

## Low-Level Usage — Controller

The `Controller` type provides frame building without any transport. This is useful for custom transports, embedded systems, or when you want full control over how frames are sent and received.

```rust
use moteus::{Controller, command::PositionCommand};

let controller = Controller::new(1);

// Build a position command
let cmd = controller.make_position_command(
    &PositionCommand::new().position(0.5).velocity(1.0),
    true  // request query response
);

// Convert to wire frame
let frame = cmd.into_frame();

// Send frame via your own transport...
// frame.arbitration_id, frame.data, frame.size
```

Parse responses back into query results:

```rust
use moteus::query::QueryResult;

// After receiving a response frame from transport...
let result = controller.parse_query(&response_frame)?;
println!("Mode: {:?}, Position: {}", result.mode, result.position);
```

## Custom Query Resolution

By default, only a limited set of registers are queried. To request additional registers, customize the `QueryFormat`:

```rust
use moteus::{BlockingController, Resolution, Register};
use moteus::query::QueryFormat;

let mut query_format = QueryFormat::default();
query_format.power = Resolution::Float;

let mut ctrl = BlockingController::new(1);
ctrl.controller.query_format = query_format;
```

For registers not in the standard `QueryFormat`, use the `extra` mechanism:

```rust
use moteus::{BlockingController, Resolution, Register};
use moteus::query::{QueryFormat, ExtraQuery};

let mut query_format = QueryFormat::default();
query_format.extra[0] = ExtraQuery {
    register: Register::Encoder1Position,
    resolution: Resolution::Float,
};

let mut ctrl = BlockingController::new(1);
ctrl.controller.query_format = query_format;
```

## Transport Configuration

### Auto-Discovery Options

Configure transport auto-detection with `TransportOptions`:

```rust
use moteus::{BlockingController, TransportOptions};
use std::time::Duration;

let opts = TransportOptions::new()
    .socketcan_interfaces(vec!["can0"])
    .timeout(Duration::from_millis(200));

let mut ctrl = BlockingController::with_options(1, &opts);
```

### Explicit Transport

You can also specify a transport directly:

```rust
use moteus::BlockingController;
use moteus::transport::socketcan::SocketCan;

let transport = SocketCan::new("can0")?;
let mut ctrl = BlockingController::new(1)
    .transport(transport);
```

## Diagnostics

The `DiagnosticStream` provides access to the moteus diagnostic protocol for reading and writing configuration:

```rust
use moteus::DiagnosticStream;

let mut stream = DiagnosticStream::new(1)?;

// Read a configuration value
let response = stream.command("conf get servo.max_current_A")?;
println!("{}", response);

// Write a configuration value
stream.command("conf set servo.max_current_A 30.0")?;
```

## Multi-Servo Coordinated Moves

The `move_to` function provides coordinated multi-servo motion:

```rust
use moteus::move_to::{move_to, MoveToOptions, Setpoint};

let setpoints = vec![
    Setpoint { id: 1, position: 0.5, velocity: None, max_torque: None },
    Setpoint { id: 2, position: -0.3, velocity: None, max_torque: None },
];

let opts = MoveToOptions::default();
move_to(&setpoints, &opts)?;
```

## API Reference

- [Rust API Reference](../reference/rust.md) — Curated summary of key types
- [moteus on docs.rs](https://docs.rs/moteus/) — Full auto-generated API documentation
- [moteus-protocol on docs.rs](https://docs.rs/moteus-protocol/) — Protocol crate documentation

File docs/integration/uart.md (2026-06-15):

# UART

In systems where CAN-FD is not available, moteus can be commanded and monitored over a TTL level UART connection.

## Default configuration

By default, moteus controllers with a sufficiently new firmware version have the following pins configured for that purpose.

* moteus-r4: aux2 a/b
* moteus-c1: aux2 b/c
* moteus-n1/moteus-x1: aux1 d/e

Serial parameters:

* Baudrate: 921600
* Data bits: 8
* Stop bits: 1
* Parity: None

## Protocol

In this mode, moteus acts as if it were a fdcanusb device on the UART.  The moteus python, C++, and rust libraries can be used directly if the operating system device name for the UART is given instead of the fdcanusb.  The only difference is that moteus permits checksums on command lines and always emits checksums on response lines.  Once any command has been sent with a checksum, all further commands require a checksum.

The checksum uses the following format:

```
data line *XX
```

Where the '*' character is followed by two hexadecimal digits.  Those are the CRC-8 using polynomial 0x97.  Sample calculation routines are:

=== "Python"

    ```python
    _CRC8_TABLE = [
        0x00, 0x97, 0xb9, 0x2e, 0xe5, 0x72, 0x5c, 0xcb,
        0x5d, 0xca, 0xe4, 0x73, 0xb8, 0x2f, 0x01, 0x96,
    ]

    def compute_crc8(data: bytes) -> int:
        """Compute CRC-8 using polynomial 0x97, nybble-at-a-time."""
        crc = 0
        for b in data:
            crc = _CRC8_TABLE[((crc >> 4) ^ (b >> 4)) & 0x0f] ^ ((crc << 4) & 0xff)
            crc = _CRC8_TABLE[((crc >> 4) ^ (b & 0x0f)) & 0x0f] ^ ((crc << 4) & 0xff)
        return crc

    ```

=== "C++"
    ```cpp
    static constexpr uint8_t kCrc8Table[16] = {
        0x00, 0x97, 0xb9, 0x2e, 0xe5, 0x72, 0x5c, 0xcb,
        0x5d, 0xca, 0xe4, 0x73, 0xb8, 0x2f, 0x01, 0x96,
    };

    static uint8_t ComputeCrc8(const char* data, size_t len) {
      uint8_t crc = 0;
      for (size_t i = 0; i < len; i++) {
        const uint8_t b = static_cast<uint8_t>(data[i]);
        crc = kCrc8Table[((crc >> 4) ^ (b >> 4)) & 0x0f] ^ (crc << 4);
        crc = kCrc8Table[((crc >> 4) ^ (b & 0x0f)) & 0x0f] ^ (crc << 4);
      }
      return crc;
    }
    ```

## Usage with moteus tools and library

To use moteus_tool or tview with a UART connection, you must specify the path to the UART device on the command line:

```bash
python -m moteus_gui.tview --fdcanusb /dev/ttyUSB0
```

or:

```bash
python -m moteus.moteus_tool --fdcanusb /dev/ttyUSB0 -t 1 --info
```

When integrating with the python library, you must manually construct a transport:

```python
fdcanusb = moteus.Fdcanusb('/dev/ttyUSB0')
c = moteus.Controller(id=1, transport=fdcanusb)
```

or for C++

```cpp
using mjbots;
moteus::Controller controller([]() {
  moteus::Controller::Options options;
  options.transport = std::make_shared<moteus::Fdcanusb>("/dev/ttyUSB0");
  return options;
}());
```

or for rust

```rust
let transport = moteus::Fdcanusb::open("/dev/ttyUSB0")?;
let mut controller = moteus::BlockingController::with_transport(1, transport);
```

For embedded (no_std) rust hosts, the `moteus-protocol` crate provides an allocation-free codec for this protocol in its `fdcanusb` module.

For usage with Arduino, see that [platform integration reference](../platforms/arduino.md).

## Caveats

### Reconfiguring

If a UART is the only means of communication, it can be challenging to configure the UART pins to a different port or a different baud rate. As with nearly all moteus configurable values, configuration changes take place *immediately*.  Thus it is recommended to first configure the new port location.  If the new port is on a lower number aux port, as soon as it is configured it will become the only means of control.  Then the host can be switched to that port in order to save configuration and reconfigure the original UART pins.

Similarly, if an error is present on a given aux port configuration, then that will disable UART control along with all other functions on that aux port, even if the error is associated with a different pin on that aux port.  It may be necessary to power cycle the device or use CAN-FD to restore control.

### Addressing

moteus emulates a subset of the fdcanusb protocol, including any configured ID and CAN prefix.  Thus if you change `id.id` or `can.prefix`, you will need to use the correct CAN IDs and prefixes in further communication with the device.

### Non-bus topology

When using UART control, only a single moteus device can be connected to a single host UART port.

### Flashing

It is not possible to flash new firmware using the UART transport.  Only CAN-FD and the SWD port with a st-link are supported.

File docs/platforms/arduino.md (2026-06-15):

# Arduino

moteus provides a simplified version of the C++ library for use with Arduino compatible microcontroller systems.

## Installation

Open the Arduino library manager, search for "moteus" and install.  Then open one of the examples and modify it.  "WaitComplete" is a good one to get started with.

## Supported hardware ##

**Microcontroller**: Nearly any board compatible with the Arduino software is supported

**CAN-FD**: The library supports:

 * CAN-FD controllers and transceivers compatible with the [acan2517FD library](https://github.com/pierremolinaro/acan2517fd)
 * The onboard ACAN_T4 peripheral on Teensy 4.x boards
 * The STM32 FDCAN HAL peripheral

**UART**: The library can drive a moteus configured as a UART server from nearly any microcontroller.

### CAN-FD: ACAN2517FD

There are two pieces of configuration that are board and controller specific.

#### Pin Assignments

The `ACAN2517FD` constructor requires that it be passed the correct pins that are used for the SPI peripheral connected to the MCP2517FD controller.  For an external controller, you can use the pins you have physically wired to the controller.  For an integrated MCP2517FD you will need to look at your board documentation.

```cpp
#define MCP2517_CS  17
#define MCP2517_INT 7
// For the Longan CANBed FD, the "SPI" peripheral determines which
// pins are used.
ACAN2517FD can(MCP2517_CS, SPI, MCP2517_INT);
```

#### CAN-FD Timing

You need to match the CAN-FD base clock rate that your adapter uses.  Different adapters have different base clock rates.

**Longan Labs CANBed FD**: This board uses a 20MHz clock

**Mikro MCP2517FD Click**: This board defaults to a 40MHz clock, but can be configured by jumper.

Regardless, you need to pass the correct clock rate using the `ACAN2517FDSettings` object.

```cpp
ACAN2517FDSettings settings(
    ACAN2517FDSettings::OSC_20MHz,
    1000ll * 1000ll,
    DataBitRateFactor::x1);

settings.mArbitrationSJW = 2;
settings.mDriverTransmitFIFOSize = 1;
settings.mDriverReceiveFIFOSize = 2;

const uint32_t errorCode = can.begin(settings, [] { can.isr(); });
```

### CAN-FD: Teensy 4.x - ACAN_T4

Configuring the Teensy 4.x library merely requires selecting which CAN-FD peripheral to use.

```
MoteusTeensyCanFd canBus(ACAN_T4::can3)
```

Where one of `can1`, `can2` or `can3` are possible.

### CAN-FD: STM32 FDCAN HAL

Integration for the STM32 FDCAN HAL periphal is currently undocumented, but some source examples exist.

### UART

When using the UART means of control, there are two options:

1. The Arduino HardwareSerial class
2. Roll your own serial port class with a similar interface

Using the Arduino serial class looks like:

```
using MyTransport = MoteusUart<HardwareSerial>;
MyTransport uart_bus(Serial1);
MoteusController<MyTransport> moteus1(uart_buf, []() {
  MoteusController<MyTransport>::Options options;
  return options;
}());
```

Implementing a custom serial class requires the following methods:

```
class MySerial {
  int available();
  int read();
  size_t write(const uint8_t* size_t);
};

using MyTransport = MoteusUart<MySerial>;
```

## Caveats

There are some caveats when controlling moteus from a microcontroller.

### Operating system connected CAN-FD adapter still required

While you can command and control moteus from the Arduino library, there is currently no mechanism to calibrate a new motor with a controller.  Thus you *must* have a CAN-FD adapter that is able to be connected to a computer with an operating system in order to run the [calibration process](../guides/calibration.md). It is also much easier to use such an adapter with tview to set the configuration and tune the PID gains.

### Teensy 4.x and STM32 FDCAN HAL require an external CAN-FD transceiver

The CAN-FD controller built into the Teensy 4.x and various STM32 peripherals is a logic level peripheral.  To operate on a CAN-FD bus, a transceiver is required in order to convert to line voltages.  Many off the shelf options are available, although beware that many require both 5V and 3V supplies.

### Termination

Many external MCP2517FD controller/transceivers do not have termination resistors.  To operate correctly, a CAN-FD bus is intended to have 2 120ohm resistors between CANL and CANH, one at each end of the bus.  Often short busses will work acceptly with only 1 termination resistor, but never with 0.

### Flash and storage limitations

With some smaller Arduino platforms, notably the Arduino Uno or Longan Labs CANBed FD, the combination of the ACAN2517FD library and the moteus library can consume a significant fraction of the flash and RAM available. For simple applications this isn’t a problem, but if you want to execute something more complex, you may be better served using a more capable Arduino compatible processor, like a [Teensy 4](https://www.pjrc.com/store/teensy41.html) or a [Nano Sense 33](https://store-usa.arduino.cc/products/nano-33-ble-sense-rev2).

## Overview video

A video overview of the process of using an Arduino with moteus can be found here:

{{ youtube("dbV0jIN8Ay4") }}

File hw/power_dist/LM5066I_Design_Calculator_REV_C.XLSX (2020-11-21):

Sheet: Instructions_Disclaimer
 | © 2014
LM5066I Design Tool- Rev. C
Typical design procedure
Typical applications require multiple passes through the design tool using MOSFET factors such as transient
thermal response and safe operating area curves. Refer to the following application reports for more detail.
Robust Hot Swap Design (http://www.ti.com/lit/ds/snvs452d/snvs452d.pdf)
LM5066I Datasheet (See "Applications and Implementation") (http://www.ti.com/lit/gpn/lm5066i)
The basic design process follows:
1. Enter operating conditions.
2. Select current limit parameters.
3. Enter MOSTFET SOA characteristics & power limit.
4. Select start up conditions (load and/or soft start). Check whether FET is operating with reasonable margin, within the SOA curve.
If not, try changing start-up conditions (soft start values, timer values), add more FETs in parallel, or switch to FET with better SOA.
5. Enter desired UVLO and OVLO values to get recommended resistor values.
6. Done
Notes
1. This worksheet is designed for use with Microsoft Excel 5.0 or later. Its use is intended to assist power supply designers in their
routine, day-to-day calculations.
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

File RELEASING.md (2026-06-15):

# Releasing moteus

Each shipped artifact (firmware, Python client, C++ client, Rust client)
carries its own [semver](https://semver.org/) version and its own release
cadence. Tags are prefixed by component:

| Component | Version source | Tag prefix |
|---|---|---|
| firmware  | `fw/moteus_hw.h` (`MOTEUS_FIRMWARE_VERSION`) | `firmware/v...` |
| python | `tools/python.bzl` (`VERSION`) | `python/v...` |
| cpp | `CMakeLists.txt` (`project(... VERSION ...)`) | `cpp/v...`  |
| rust | `lib/rust/Cargo.toml` (`[workspace.package] version`) | `rust/v...` |

Firmware, cpp, and rust pre-releases use semver suffixes (`1.0.0-rc.1`,
`1.0.0-beta.1`); the python package uses normalized PEP 440 forms instead
(`1.0.0rc1`, see [Python version strings](#python-version-strings)). For
firmware, the on-wire version (register 0x101) is the packed
`MAJOR.MINOR.PATCH` only,
so a `-rc.N` build of `1.0.0` reports exactly the same value over CAN as the
final `1.0.0`. They are ABI-equivalent on purpose; the build identity comes
from `fw/git_info.h` (commit SHA + dirty flag + timestamp).

## Firmware ABI version vs release version

`MOTEUS_FIRMWARE_VERSION` in `fw/moteus_hw.h` is the **firmware ABI
version** — what register 0x101 reports over CAN. It is independent of
the firmware release version (the `firmware/vX.Y.Z` git tag).

The ABI constant only bumps when the calibration process changes, or
configuration fields either change interpretation or require
conversion across upgrades.

By convention every ABI bump on this project has been
backwards-compatible in one direction: a newer client can talk to any
older firmware, but an older client cannot calibrate against newer
firmware and may or may not be able to successfully command a newer
firmware. So an ABI bump maps to a **MINOR** semver step. A real ABI
break that prevents new clients from talking to old firmware would be
MAJOR — that has not happened yet.

`SUPPORTED_ABI_VERSION` in `lib/python/moteus/moteus_tool.py` is the
highest firmware ABI that `moteus_tool --calibrate` knows how to handle.
In the source tree it tracks `MOTEUS_FIRMWARE_VERSION` exactly: when
firmware feature work bumps the ABI constant, the same commit (or
adjacent commit) bumps `SUPPORTED_ABI_VERSION` to match and adds the
new `FirmwareUpgrade.fix_config` rule.

The helper bumps both at once:

```bash
python3 utils/encode_firmware_version.py update \
    --firmware 1.1.0 --supported-abi 1.1.0
git commit -am "Bump firmware ABI to 1.1.0 for new <feature>"
```

`utils/release.py firmware <bump>` never modifies these constants. It
**validates** that `MOTEUS_FIRMWARE_VERSION`'s M.m is not greater than
the M.m of the release being tagged. The release's M.m may legitimately
move ahead of the ABI's M.m (a non-ABI-affecting MINOR release), but
the reverse — ABI ahead of release — would mean the firmware is
shipping with a newer ABI than its version number claims.

## When you do (and don't) need a Python release

The on-wire compatibility check that protects users is:

> published-moteus_tool `SUPPORTED_ABI_VERSION` ≥ firmware's reported
> ABI (register 0x101)

So:

- **Firmware patch release, no ABI change**: no Python release needed.
- **Firmware MINOR release, no ABI change**: no Python release needed.
- **Firmware MINOR release, ABI changed**: Python release needed so the
  published wheel knows about the new ABI. Treat it as a MINOR Python
  bump (it adds a capability — the tool now accepts firmwares it used
  to refuse).
- **Firmware MAJOR release**: Python release needed (still MINOR on the
  Python side; Python's own major version is a separate concern that
  moves only on Python API breaks).

Until the next Python release ships, users running `pip install moteus`
with the new firmware will hit the friendly "moteus_tool needs to be
upgraded" error from `SUPPORTED_ABI_VERSION` — which is correct
behavior, not a regression.

Python (and C++/Rust) releases are also of course necessary if the
functionality of the relevant library is improved or bugs are fixed.
The Rust client does not perform calibration, so it has no
`SUPPORTED_ABI_VERSION` concern — like C++, it only needs a release
when its own functionality changes.

## Cutting a release

Run the helper from the repo root, then push:

```bash
# patch bump (1.0.0 -> 1.0.1)
utils/release.py firmware patch

# minor bump
utils/release.py python minor

# start a pre-release cycle (explicit)
utils/release.py firmware 1.1.0-rc.1

# iterate a pre-release (1.1.0-rc.1 -> 1.1.0-rc.2)
utils/release.py firmware rc

# graduate a pre-release to its final release (1.1.0-rc.2 -> 1.1.0)
utils/release.py firmware patch
```

The `patch` bump is overloaded for convenience: when current is already a
pre-release, it strips the suffix instead of incrementing the patch byte
(matches npm/cargo conventions). `minor` and `major` always advance
M.m.p as you'd expect, regardless of any pre-release suffix.

The script:

1. Determines the current release version (from the latest `firmware/v*`
   tag for firmware, or from the version file for python/cpp).
2. Computes the new version (or accepts an explicit one).
3. For firmware: validates `MOTEUS_FIRMWARE_VERSION` matches the new
   release's M.m.p; refuses to tag otherwise.
4. For python/cpp/rust: updates the version file(s) in place. For rust
   this is `lib/rust/Cargo.toml` (the workspace version plus the
   inter-crate dependency requirements) and the matching package
   entries in `lib/rust/Cargo.lock`.
5. Commits (if the files changed) and creates the annotated tag.
6. Prints the `git push` commands.

Inspect the diff and tag before pushing.

```bash
git push origin HEAD
git push origin firmware/v1.0.1
```

The matching `build-<component>-release` workflow then builds the
artifact and creates a GitHub Release **as a draft**.  Drafts are not
visible to users browsing the Releases page or to `pip`/`FetchContent`
consumers — they exist only on the maintainer's view of the page.

You can also kick off a release from the GitHub UI via the
[`Release`](.github/workflows/release.yml) workflow — it runs the same
script in CI, useful when releasing from somewhere without your local
toolchain.

## Promoting a draft release to public

After the build workflow finishes, validate the draft locally:

1. Go to the repo's Releases page → the draft will show under "Draft"
   at the top.  Download the attached artifacts.
2. For firmware: flash on representative hardware and run your
   validation suite.  For python: `pip install` the wheel into a fresh
   venv and exercise `moteus_tool` against a device.  For cpp: build a
   downstream project against the tag.  For rust: build a downstream
   project against the tag (`moteus = { git = ..., tag = "rust/vX.Y.Z" }`)
   and exercise it against a device.
3. When satisfied, publish.  Either click "Publish release" in the UI,
   or:

   ```bash
   gh release edit firmware/v1.0.0 --draft=false
   ```

If something is wrong, abort instead of publishing:

```bash
gh release delete firmware/v1.0.0 --yes
git push --delete origin firmware/v1.0.0
git tag -d firmware/v1.0.0
# ...fix the issue, then re-tag
```

For python, **promoting the draft is what triggers the PyPI publish**.
The `publish-python-pypi.yml` workflow listens for the `release:
published` event, downloads the wheel and sdist attached to the
release, and uploads them to PyPI via OIDC. Do not click "Publish
release" on a python draft until you intend the wheel to land on
PyPI — PyPI is append-only, you cannot un-publish.

Likewise for rust, **promoting the draft is what triggers the
crates.io publish**. The `publish-rust-crates.yml` workflow checks out
the release tag and runs `cargo publish --workspace` via OIDC trusted
publishing. crates.io is also append-only — a published version can be
yanked but never deleted or reused.

## Cutting a maintenance branch

After every firmware MAJOR or MINOR release, cut a maintenance branch so
that future bugfixes can be backported to it without dragging in unrelated
`main` work:

```bash
utils/cut_release_branch.py firmware/v1.0.0
git push origin release/firmware-1.0.x
```

For a 1.0.1 patch release: land the fix on `main`, then:

```bash
git checkout release/firmware-1.0.x
git cherry-pick <sha>
utils/release.py firmware patch
git push origin HEAD release/firmware-1.0.x
git push origin firmware/v1.0.1
```

## Updating SUPPORTED_ABI_VERSION

`SUPPORTED_ABI_VERSION` in `lib/python/moteus/moteus_tool.py` is bumped
together with `MOTEUS_FIRMWARE_VERSION` during the feature work that
introduces the ABI change (see "Firmware ABI semantics" above). It is
not a release-time concern; by the time you run `utils/release.py
firmware ...`, the constants should already match.

If they have somehow drifted, fix them in a single source commit before
tagging:

```bash
python3 utils/encode_firmware_version.py update \
    --firmware <version> --supported-abi <version>
git commit -am "Sync firmware ABI version constants"
```

The published moteus_tool wheel doesn't pick up the new
`SUPPORTED_ABI_VERSION` until the next `python/v*` release. Until then,
users running `pip install moteus` will hit the friendly
"moteus_tool needs to be upgraded" error when calibrating against the
newer firmware. That's the intended behavior.

## What each workflow does

- `release.yml` — manual `workflow_dispatch` to bump and tag from CI.
- `build-firmware-release.yml` — fires on `firmware/v*`. Builds via
  `tools/bazel build --config=target -c opt //:target` and attaches
  the two flashable ELFs (`moteus-fw-<version>+g<sha>.elf` and
  `moteus-bl-<version>+g<sha>.elf`) to the Release. The `+g<sha>`
  portion is semver build metadata — the 10-char git short SHA of
  the tagged commit, ignored for version precedence.
- `build-python-release.yml` — fires on `python/v*` tag push. Builds
  both `//lib/python:bdist_wheel` (the `moteus` package) and
  `//utils/gui:bdist_wheel` (the `moteus_gui` package) and attaches
  the wheels + sdists for both to a draft Release. The two packages
  share the version from `tools/python.bzl` and ship in lockstep.
- `publish-python-pypi.yml` — fires when a `python/v*` Release is
  promoted out of draft. Downloads the attached wheels + sdists and
  uploads them to PyPI via OIDC trusted publishing (one upload covers
  both packages). See [Publishing to PyPI](#publishing-to-pypi) below.
- `build-cpp-release.yml` — fires on `cpp/v*`. Creates a Release page;
  GitHub auto-attaches whole-repo source archives. The C++ client is
  header-only and is normally consumed via `FetchContent` pointing at the
  tag.
- `build-rust-release.yml` — fires on `rust/v*` tag push. Runs
  `cargo package --workspace` and attaches the three `.crate` files
  (`moteus`, `moteus-derive`, `moteus-protocol`) to a draft Release.
  The three crates share the version from `lib/rust/Cargo.toml` and
  ship in lockstep.
- `publish-rust-crates.yml` — fires when a `rust/v*` Release is
  promoted out of draft. Checks out the tag and runs
  `cargo publish --workspace`, which publishes the three crates to
  crates.io in dependency order via OIDC trusted publishing. See
  [Publishing to crates.io](#publishing-to-cratesio) below.

## Python version strings

PyPI requires [PEP 440](https://peps.python.org/pep-0440/) versions, which
are *not* identical to semver. Use the PEP 440 forms when releasing the
Python package:

| Kind | Semver | PEP 440 (use this for python) |
|---|---|---|
| Release | `1.0.0` | `1.0.0` |
| Release cand. | `1.0.0-rc.1`  | `1.0.0rc1` |
| Beta | `1.0.0-beta.1`| `1.0.0b1` |
| Alpha | `1.0.0-alpha.1`| `1.0.0a1` |
| Dev | `1.0.0-dev.1` | `1.0.0.dev1` |
| Post | (n/a) | `1.0.0.post1` |

The firmware, C++, and Rust tags continue to use semver
(`firmware/v1.0.0-rc.1`, `rust/v1.0.0-rc.1` — crates.io requires it).
They're independent components and free to use different conventions.

```bash
# python pre-release
utils/release.py python 1.0.0rc1
# tag: python/v1.0.0rc1

# firmware pre-release (semver)
utils/release.py firmware 1.0.0-rc.1
# tag: firmware/v1.0.0-rc.1
```

## Publishing to PyPI

PyPI publishing uses [trusted publishing](https://docs.pypi.org/trusted-publishers/)
via OIDC, so no API token is stored in this repo.

A python release covers two PyPI projects — `moteus` (the client
library) and `moteus_gui` (the GUI tools, which depends on `moteus`).
They share a single version from `tools/python.bzl` and ship together.

**One-time setup** (do this for *both* projects):

1. Sign in to PyPI as a maintainer of the project.
2. Project settings → Publishing → Add a new pending publisher (or
   trusted publisher if the project exists). Configure:
   - Owner: `mjbots`
   - Repository name: `moteus`
   - Workflow name: `publish-python-pypi.yml`
   - Environment name: `pypi`
3. Repeat for the second project — both `moteus` and `moteus_gui`
   need the same trusted-publisher entry. A single workflow run
   uploads to both, but each PyPI project authenticates the OIDC
   token independently.
4. In this GitHub repo: Settings → Environments → New environment
   named `pypi`. The environment exists so PyPI's trusted-publishing
   config has something to bind to; no required reviewers are needed
   because the "Publish release" action on the draft is the gate.

After setup, the python release flow is:

1. Push a `python/v*` tag → `build-python-release.yml` builds both
   wheels + sdists (`moteus-X.Y.Z*` and `moteus_gui-X.Y.Z*`) and
   creates a draft GitHub Release with all four files attached.
2. Validate locally (`pip install` both wheels into a fresh venv,
   exercise `moteus_tool` against a device, run `tview`).
3. Publish the draft via the GitHub UI or
   `gh release edit python/vX.Y.Z --draft=false`.
4. Promoting the draft fires `publish-python-pypi.yml`, which
   downloads the attached wheels + sdists and uploads them to PyPI
   via OIDC. PyPI authenticates each upload against the matching
   project's trusted-publisher config.

A pre-release version (anything PEP 440 considers pre-release, e.g.
`1.0.0rc1`) goes to PyPI but `pip install moteus` won't pick it up
unless the user passes `--pre`. So pre-releases are safe to publish.

PyPI is append-only — you can yank a release but cannot delete it or reuse
the version number. The environment-gate is the safety net.

## Publishing to crates.io

crates.io publishing uses
[trusted publishing](https://crates.io/docs/trusted-publishing) via
OIDC, so no API token is stored in this repo — the same model as PyPI.

A rust release covers three crates — `moteus` (the client library),
`moteus-protocol` (the no_std protocol types), and `moteus-derive`
(the proc macros). They share a single version from
`lib/rust/Cargo.toml` and ship together; `cargo publish --workspace`
publishes them in dependency order automatically.

**Bootstrap**: crates.io only allows trusted publishing to be
configured on a crate that already exists, so the *very first* publish
of each crate must be done manually by a maintainer:

```bash
cd lib/rust
cargo publish --workspace --locked   # uses your `cargo login` token
```

**One-time setup** (after the first publish, for *each* of the three
crates):

1. Sign in to crates.io as an owner of the crate.
2. Crate → Settings → Trusted Publishing → Add. Configure:
   - Repository owner: `mjbots`
   - Repository name: `moteus`
   - Workflow filename: `publish-rust-crates.yml`
   - Environment: `crates-io`
3. In this GitHub repo: Settings → Environments → New environment
   named `crates-io` (analogous to the `pypi` environment; the
   "Publish release" action on the draft is the gate).

After setup, the rust release flow is:

1. Push a `rust/v*` tag → `build-rust-release.yml` packages the three
   crates and creates a draft GitHub Release with the `.crate` files
   attached.
2. Validate locally (point a downstream project's `Cargo.toml` at the
   tag, exercise it against a device).
3. Publish the draft via the GitHub UI or
   `gh release edit rust/vX.Y.Z --draft=false`.
4. Promoting the draft fires `publish-rust-crates.yml`, which checks
   out the tag, exchanges an OIDC token with crates.io, and runs
   `cargo publish --workspace --locked`.

A pre-release version (`1.0.0-rc.1`) goes to crates.io but cargo will
not select it for a normal requirement like `moteus = "1.0"`; users
must opt in with an explicit pre-release requirement
(`moteus = "1.0.0-rc.1"`). So pre-releases are safe to publish.

crates.io is append-only — you can yank a version but cannot delete it
or reuse the version number. The environment-gate is the safety net.

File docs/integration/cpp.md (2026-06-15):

# C++ Client Library

moteus provides a C++ library that can be used to command and control moteus controllers using a supported CAN-FD adapter.

## Integration

The moteus C++ library is header only, so there are several possible options for integrating the C++ library into your project.

**Copy the source files**: One option is to copy all the relevant headers into your source tree:

- [https://github.com/mjbots/moteus/tree/main/lib/cpp/mjbots/moteus](https://github.com/mjbots/moteus/tree/main/lib/cpp/mjbots/moteus)

**CMake**: There exists a top level `CMakeLists.txt` file that can be used with [CMake](https://cmake.org)'s `FetchContent` to incorporate the headers into your project.

```
include(FetchContent)
FetchContent_Declare(
  moteus
  GIT_REPOSITORY https://github.com/mjbots/moteus.git
  # Pin to a specific commit for a reproducible build.  The trailing
  # comment names the corresponding C++ release tag for readers.
  GIT_TAG        a1b2c3d4e5f6789012345678901234567890abcd  # cpp/v1.0.0
)

FetchContent_MakeAvailable(moteus)

add_executable(myproject myproject.cc)
target_link_libraries(myproject moteus::cpp)
```

Pin to the commit hash rather than the tag itself.  Tags are mutable
in principle (they can be force-pushed or recreated), so a hash is the
only reference that guarantees a reproducible fetch.  The
`# cpp/vX.Y.Z` trailing comment keeps the version human-readable and
is what you update — together with the hash — when bumping to a new
release.

The latest C++ release and its commit hash are listed on the
[Releases page](https://github.com/mjbots/moteus/releases) — filter
the page by typing `cpp/` to see only C++ releases.

**bazel**: moteus does export [bazel](https://bazel.build) `BUILD` files and can be integrated into bazel projects using that mechanism as well.

## Usage

Basic usage is similar, although slightly different to the [python](python.md) library.  A minimal example follows:

```cpp
#include <iostream>
#include <unistd.h>
#include "moteus.h"

namespace moteus = mjbots::moteus;

int main(int argc, char** argv) {
  moteus::Controller::DefaultArgProcess(argc, argv);

  moteus::Controller c([]() {
    moteus::Controller::Options options;
    options.id = 1;
    return options;
  }());

  moteus::PositionMode::Command command;
  command.position = std::numeric_limits<double>::quiet_NaN();

  while (true) {
    const auto maybe_result = c.SetPosition(command);
    if (maybe_result) {
      const auto& v = maybe_result->values;
      std::cout << "Mode: " << v.mode
                << " Fault: " << v.fault
                << "Position: " << v.position
                << " Velocity: " << v.velocity
                << "\n";
    }
    ::usleep(10000);
  }
  return 0;
}
```

## Specifying alternate query registers

By default, only a subset of registers are queried by the library.

### Common register selection

To select other common options you can either (a) change the default query resolution or (b) pass an "override" query resolution.

### Option (a): Change the default

```cpp
moteus::Controller c([]() {
  moteus::Controller::Options options;
  options.query_format.power = moteus::kFloat;
  return options;
}());
```

### Option (b): Specify an "override"

```cpp
moteus::Controller c;
moteus::PositionMode::Command command;
moteus::Query::Formay query_override;

query_override.power = moteus::kFloat;
c.SetPosition(command, nullptr, &query_override);
```

### Less common register selection

For registers which do not have predefined fields in `Query::Format`, you can use the `extra` mechanism through either the constructor options or override argument.

```cpp
moteus::Controller c([]() {
  moteus::Controller::Options options;

  options.query_format.extra[0].register_number = moteus::Register::kAux1AnalogIn1;
  options.query_format.extra[0].resolution = moteus::kFloat;

  return options;
}());
```

## Specifying alternate command registers

As with queries, by default, only a subset of registers are sent with `SetPosition` or `MakePosition` commands.  Without additional work, only "position" and "velocity" are sent.  To select others, they can either be changed through (a) the defaults or by (b) overriding them.

### Option (a): Change the default

```cpp
moteus::Controller c([]() {
  moteus::Controller::Options options;
  options.position_format.feedforward_torque = moteus::kFloat;
  return options;
}());

moteus::PositionMode::Command command;
command.position = std::numeric_limits<double>::quiet_NaN();
command.velocity = 0.0;
command.feedforward_torque = 0.1;

c.SetPosition(command);
```

### Option (b): Specify an "override"

```cpp
moteus::Controller c;

moteus::PositionMode::Command command;
command.position = std::numeric_limits<double>::quiet_NaN();
command.velocity = 0.0;
command.feedforward_torque = 0.1;

moteus::PositionMode::Format format;
format.feedforward_torque = moteus::kFloat;

c.SetPosition(command, &format);
```

## Alternate Usage Modes

Like the python library, the C++ library has two modes of operation.  One designed for ease of use, and the other for maximizing bus utilization and command rate.  The former are the `Set*` variant methods used above.  Like python, there exist `Make*` variant methods which generate a frame, but do not send it.  Those can be used with a manually constructed transport.

```cpp
auto transport = moteus::MakeSingletonTransport();

moteus::Controller c([&]() {
  moteus::Controller::Options options;
  options.transport = transport;
  return options;
}());

std::vector<moteus::CanFdFrame> commands_to_send;
std::vector<moteus::CanFdFrame> replies_to_receive;

moteus::PositionMode::Command command;
commands_to_send.push_back(c.MakePosition(command));

transport->BlockingCycle(
  commands_to_send.data(),
  commands_to_send.size(),
  &replies_to_receive);
```

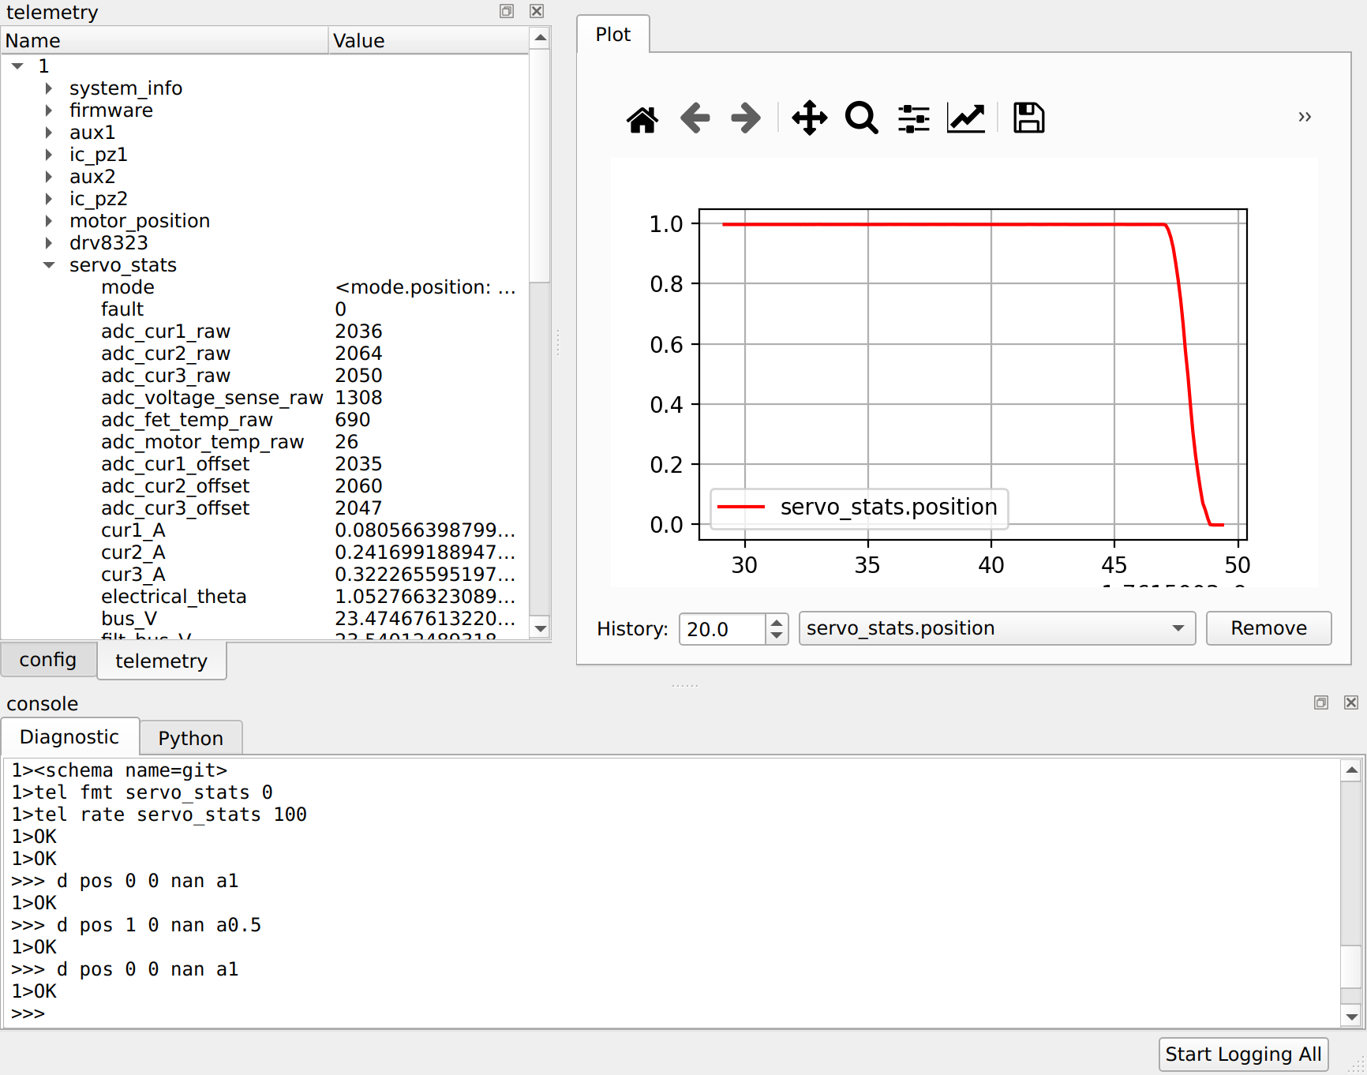
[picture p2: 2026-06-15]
docs/guides/images/tview-overview-orig.png

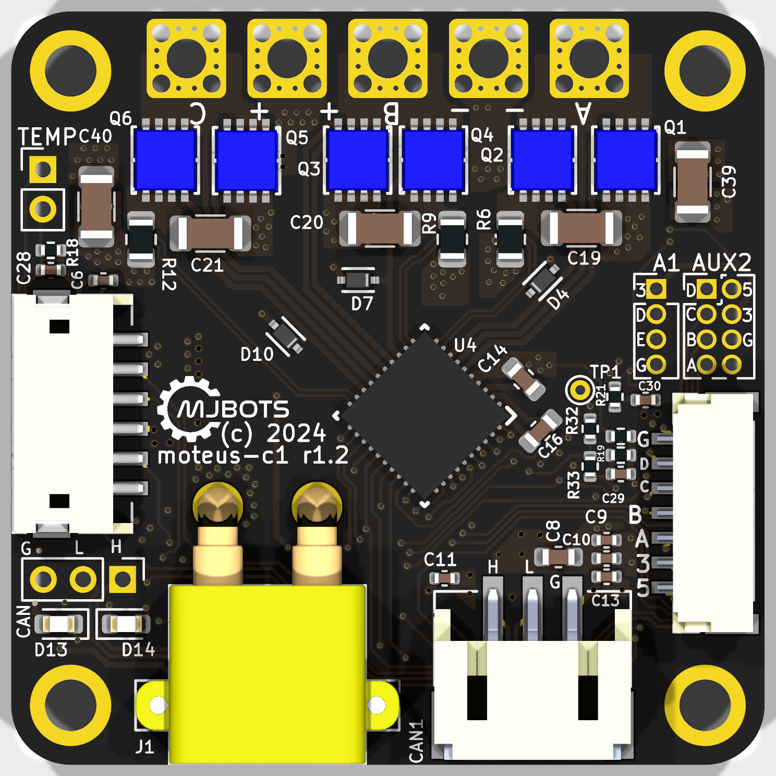
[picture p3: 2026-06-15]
docs/reference/c1/moteus-c1-base.png

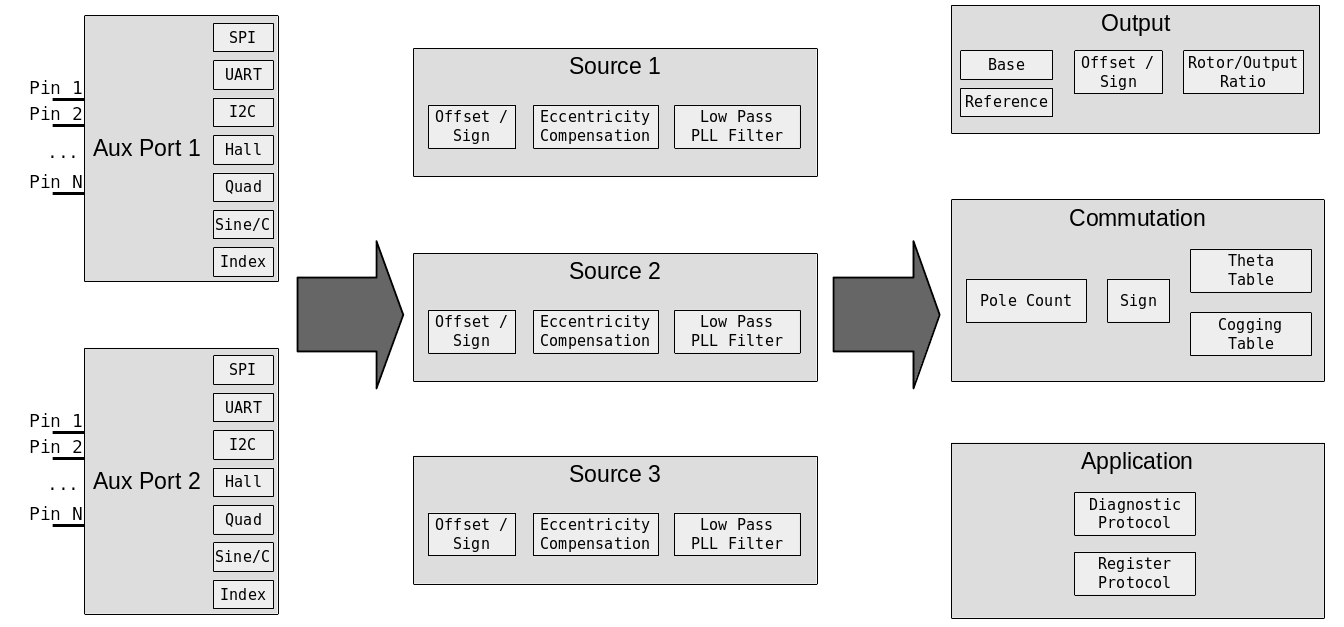
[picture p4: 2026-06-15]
docs/io_structure.png

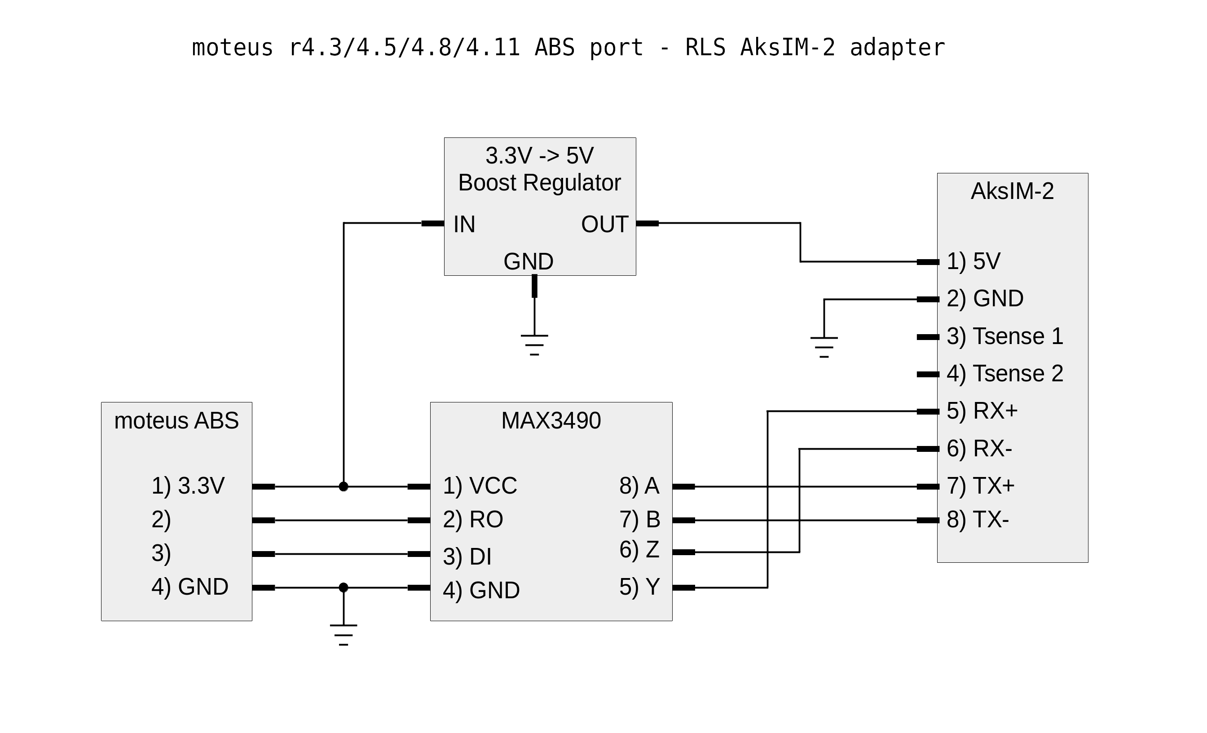
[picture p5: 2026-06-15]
docs/aksim2_adapter.png

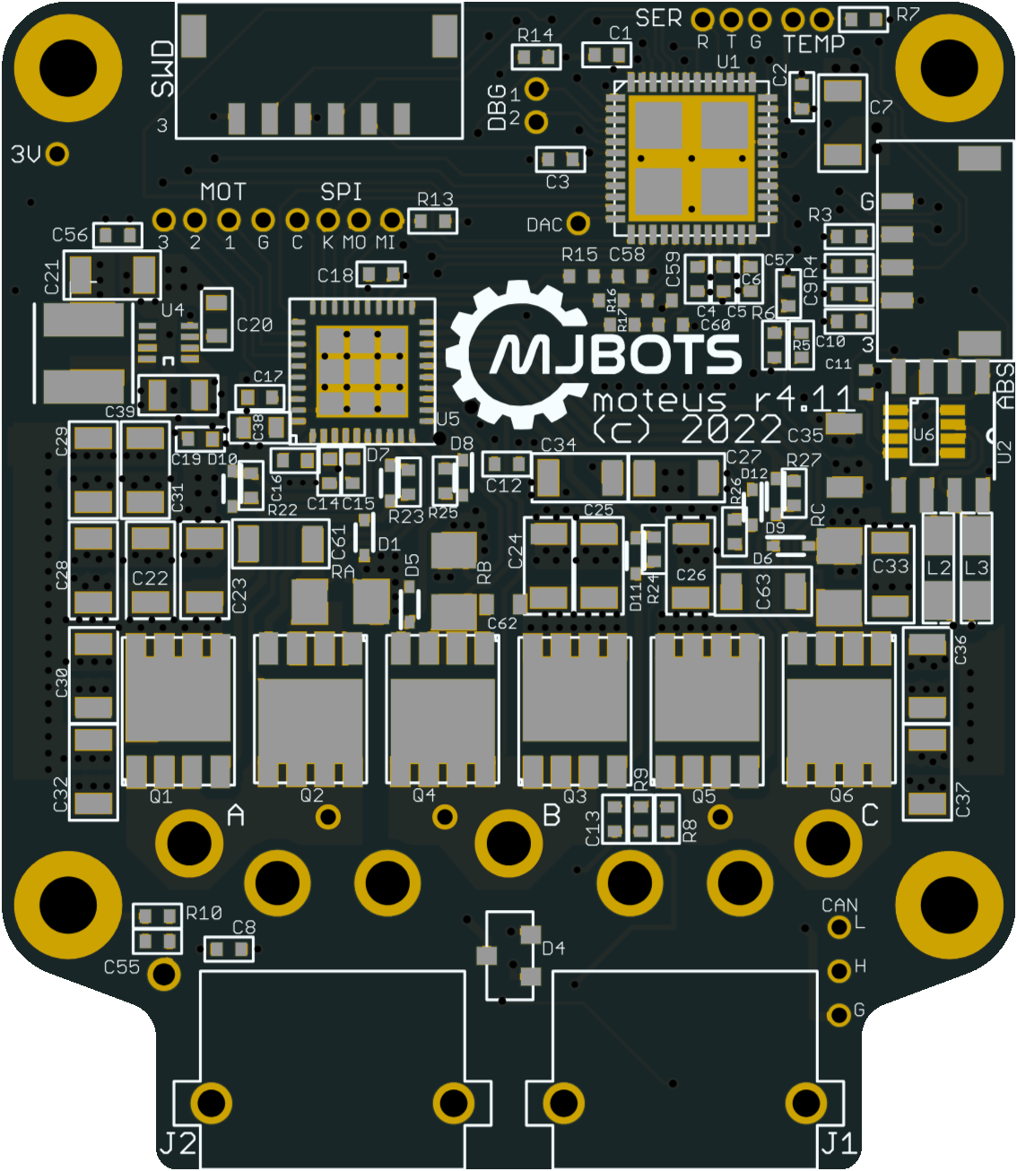
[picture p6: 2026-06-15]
docs/reference/r4/moteus-r4-front-base.png

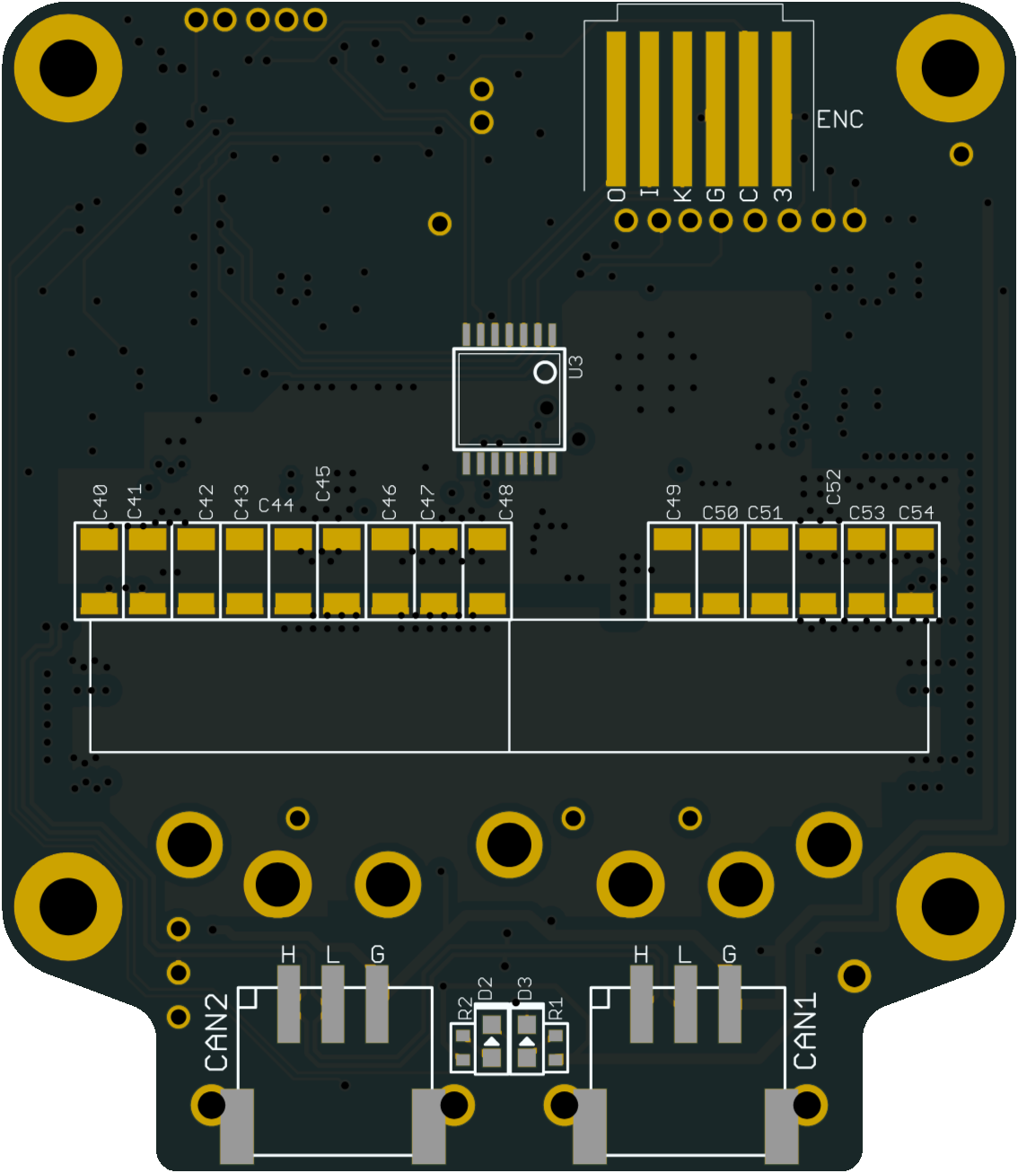
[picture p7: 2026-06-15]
docs/reference/r4/moteus-r4-back-base.png

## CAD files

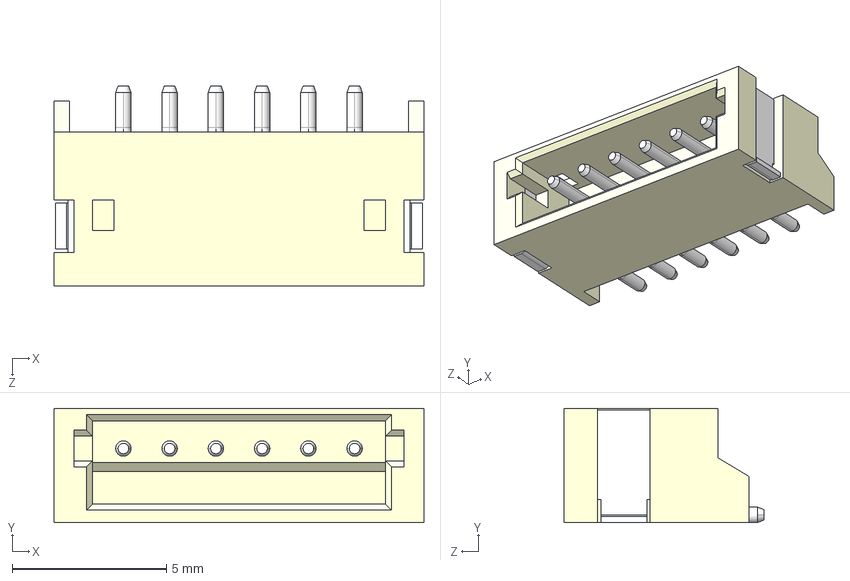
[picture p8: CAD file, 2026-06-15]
hw/c1/3d/S6B-ZR-SM4A-TF_LF__SN_.step
12.0 x 3.70 x 6.50 mm

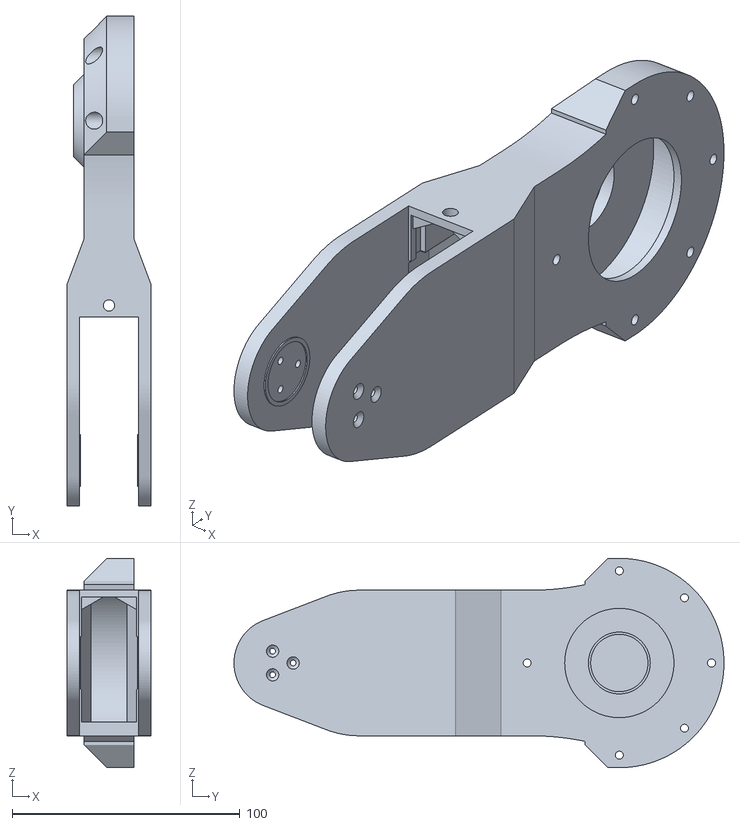
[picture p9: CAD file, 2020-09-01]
hw/mk2_leg/mk2_leg_20200825/upper_leg.stl
37.0 x 215.3 x 92.0

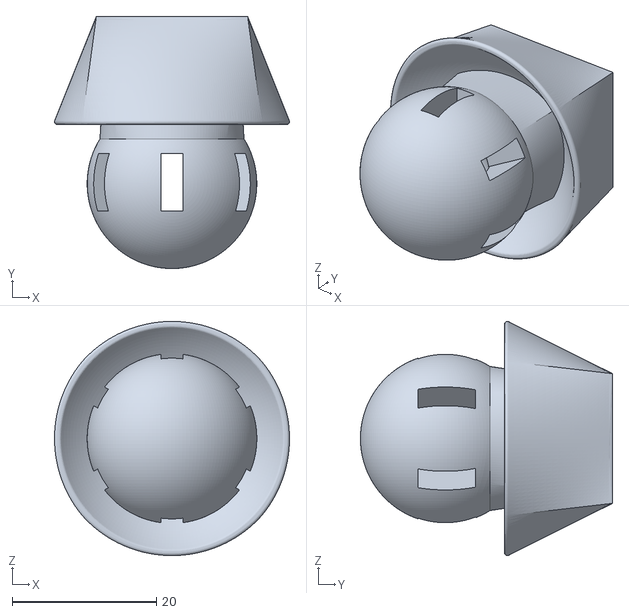
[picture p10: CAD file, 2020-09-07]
hw/mk2_leg/mk2_leg_20200905/foot_bracket.stl
32.6 x 35.0 x 32.5

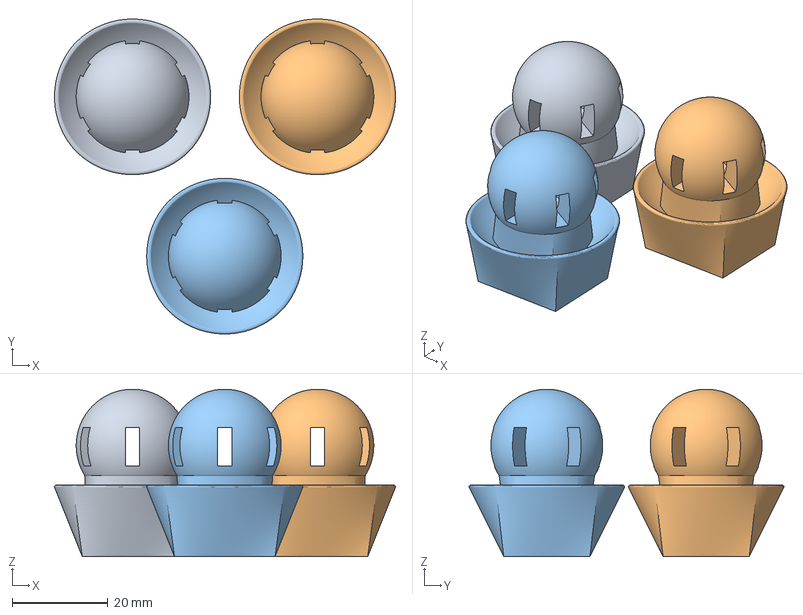
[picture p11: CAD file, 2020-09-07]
hw/mk2_leg/mk2_leg_20200907/3x_foot_bracket.3mf
71.3 x 65.8 x 35.0 mm

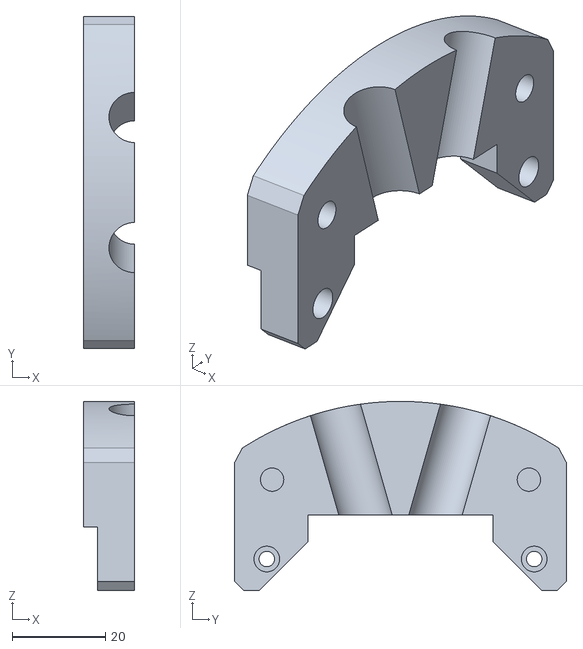
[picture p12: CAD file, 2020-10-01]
hw/mk2_leg/mk2_leg_20200924/upper_conduit_capture.stl
11.0 x 71.1 x 40.5

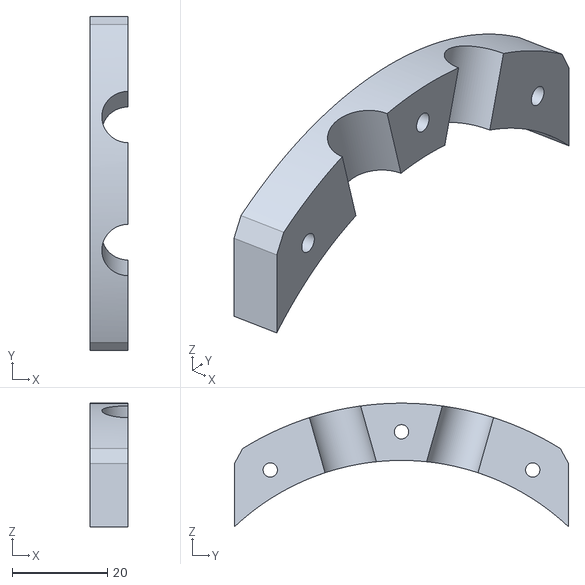
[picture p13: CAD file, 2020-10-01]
hw/mk2_leg/mk2_leg_20200926/upper_conduit_capture.stl
8.00 x 70.0 x 25.9

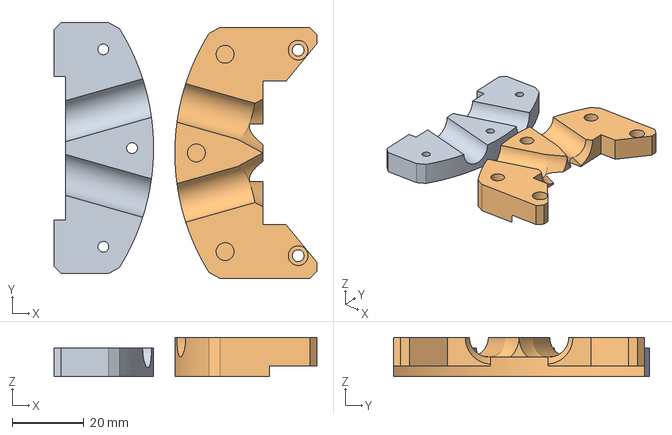
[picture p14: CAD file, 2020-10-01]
hw/mk2_leg/mk2_leg_20200929-2/knee_conduit.3mf
73.3 x 71.4 x 11.0 mm
knee_conduit_top.stl
knee_conduit_capture.stl

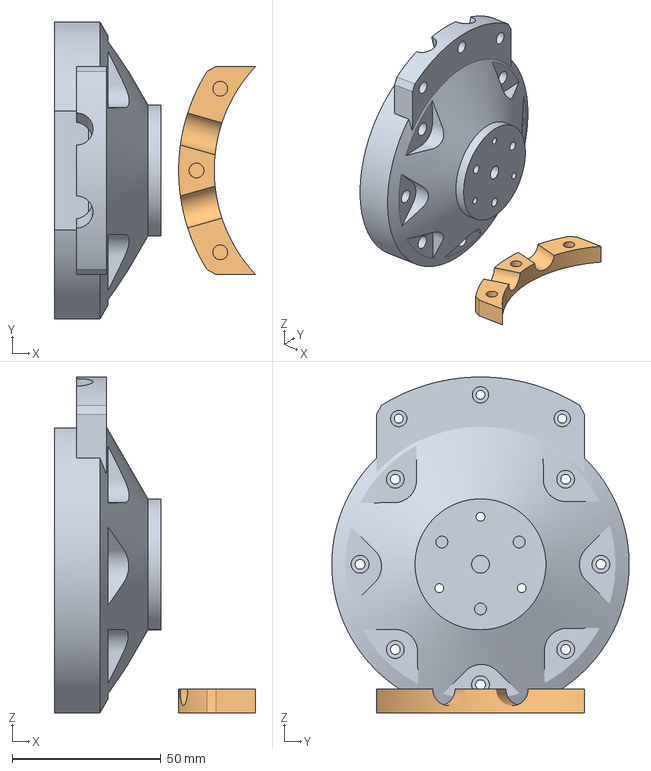
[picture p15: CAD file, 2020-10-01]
hw/mk2_leg/mk2_leg_20200929/upper_motor_joint.3mf
67.7 x 100.0 x 113.0 mm
upper_motor_joint.stl
upper_conduit_capture.stl

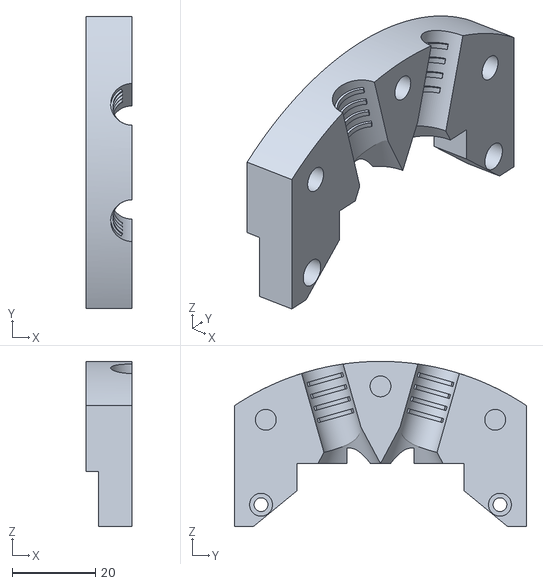
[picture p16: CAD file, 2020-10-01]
hw/mk2_leg/mk2_leg_20200930/knee_conduit_capture.stl
11.0 x 70.0 x 39.6

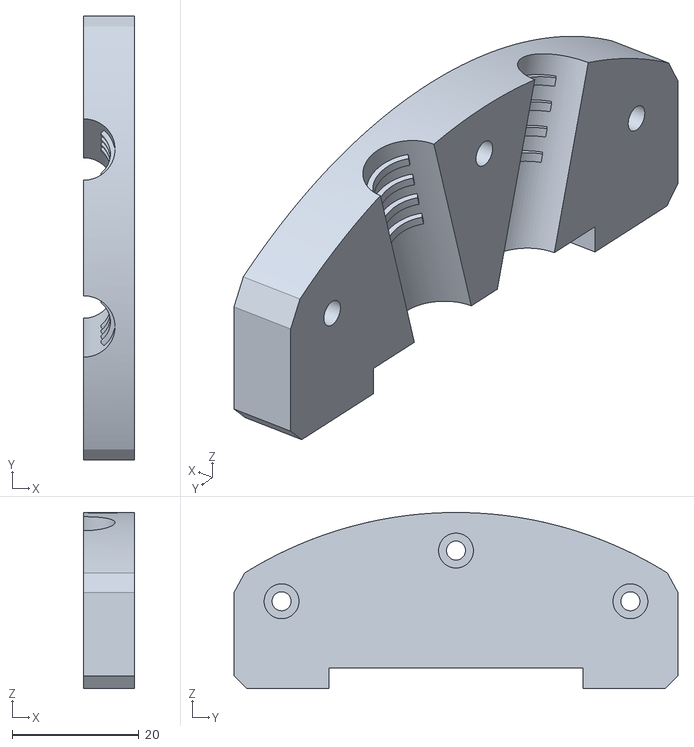
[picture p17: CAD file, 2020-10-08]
hw/mk2_leg/mk2_leg_20201008/shoulder_conduit_top.stl
8.00 x 70.0 x 27.8

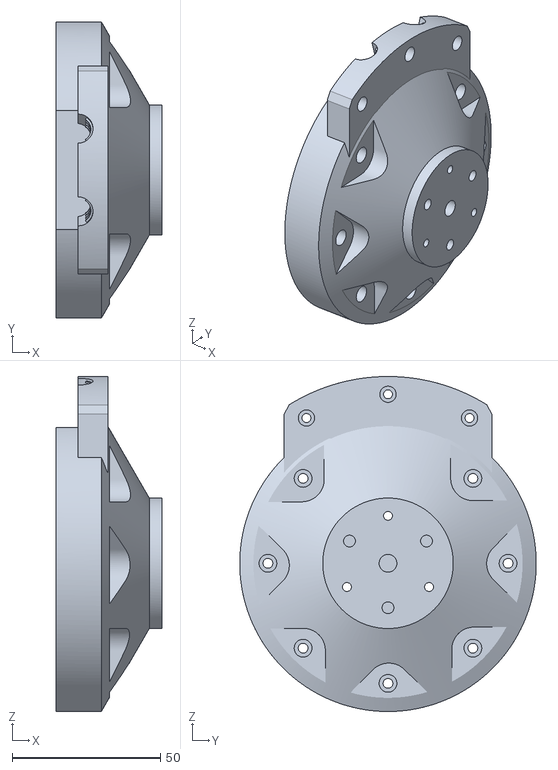
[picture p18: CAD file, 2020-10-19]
hw/mk2_leg/mk2_leg_20201009/upper_motor_joint.stl
35.8 x 100.0 x 113.0

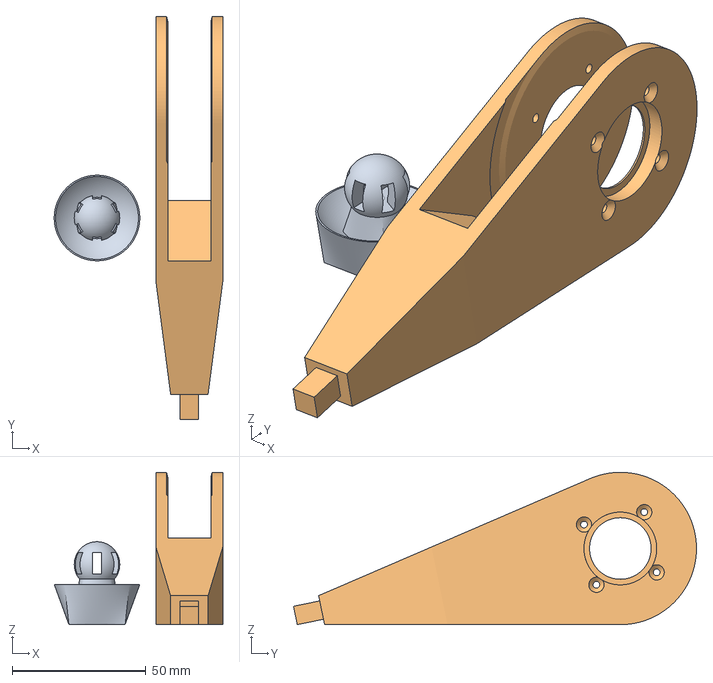
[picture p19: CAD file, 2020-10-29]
hw/mk2_leg/mk2_leg_20201019/lower_leg_and_bracket.3mf
63.0 x 150.6 x 56.9 mm
foot_bracket.stl
lower_leg.stl

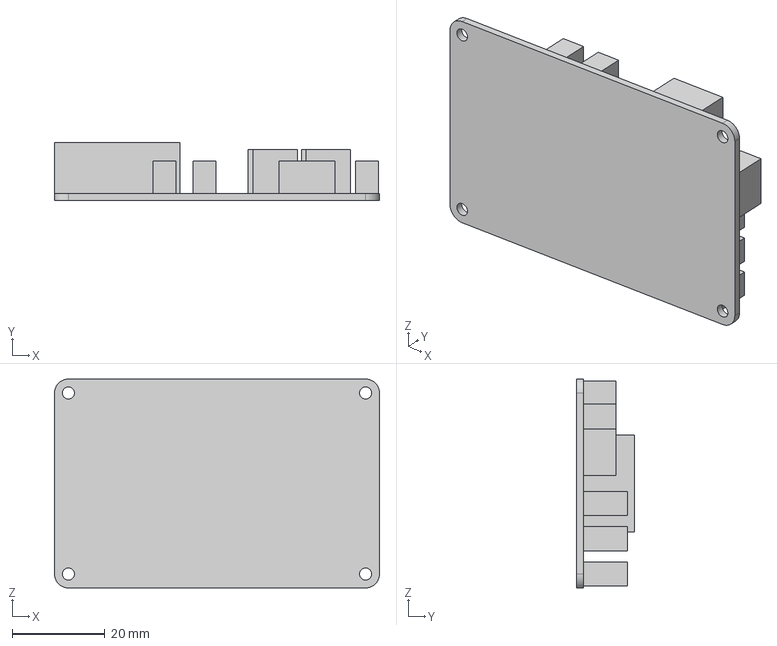
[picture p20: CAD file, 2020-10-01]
hw/power_dist/r3.1/power_dist_r3_1.step
70.0 x 12.5 x 45.0 mm

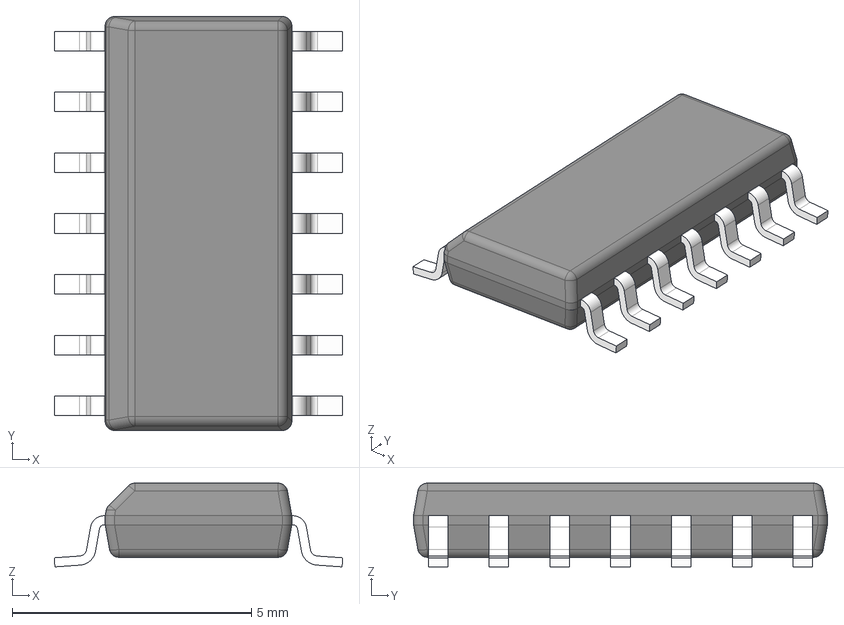
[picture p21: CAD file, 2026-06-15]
hw/x1/3d/D0014A.stp
6.03 x 8.65 x 1.75 mm
BODY-SO
LEAD-SO x 14
PIN1-ID

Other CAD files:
hw/mk2_leg/mk2_leg_20201004/upper_conduit_capture.3mf
hw/c1/3d/DRB0008F.stp
hw/mk2_leg/mk2_leg_20200825/lower_leg.stl
hw/mk2_leg/mk2_leg_20200905/lower_leg_and_bracket.3mf
hw/c1/3d/21-0487A_MXM.step
hw/c1/3d/DSE0006A.stp
hw/c1/3d/IND_4018-WE-LQS_WRE.step
hw/c1/3d/RTA0040B.stp
hw/c1/3d/S3B-PH-SM4-TB_LF__SN_.step
hw/c1/3d/SM07B-GHS-TB-LF--SN---3DModel-STEP-56544.STEP
hw/c1/3d/SOD-523_STM.step
hw/c1/3d/TSON Advance.step
hw/c1/3d/TSSOP14_OSM.step
hw/c1/3d/UFQFPN-48_7X7X0P55MM.step
hw/c1/3d/XT30PW-M.step
hw/c1/r1.2/20240305-moteus-c1-r1_2.step
hw/controller/r4.5/20210124-moteus-controller-r45-mechanical.step
hw/mk2_leg/3dprint/20200825-lower_leg_and_bracket.3mf
hw/mk2_leg/3dprint/20200825-upper_leg.3mf
hw/mk2_leg/3dprint/20201009-shoulder_conduit.3mf
hw/mk2_leg/3dprint/20201009-upper_motor_joint.3mf
hw/mk2_leg/mk2_leg_20200825/foot_bracket.stl
hw/mk2_leg/mk2_leg_20200905/lower_leg.stl
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

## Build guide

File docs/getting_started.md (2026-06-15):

# Getting started with the moteus controller #

Binary versions of `tview` and `moteus_tool` can be installed for most
platforms (desktop Linux, Windows, Mac) via python using the
`moteus_gui` package.

```
pip3 install moteus_gui
```

If you have a Raspberry Pi, see the [instructions here](raspberry_pi.md).

# Running tview #

tview lets you configure and inspect the state of the controller.  It
can be run like:

```
python3 -m moteus_gui.tview --devices=1
```

(Your pip may have installed a `tview` script into your path which you
could also use).

By default, it attempts to detect an attached fdcanusb to communicate
with the target.

tview has three panes, left, right, and bottom.  Further, the left
pane has two tabs.

Left pane, right tab (the default) shows a hierarchical tree of all
telemetry items.

Left pane, left tab shows a hierarchical tree of all configurable
parameters.  Parameter values can be updated by double clicking on
their value and entering a new one.

The right pane shows real time plots of telemetry items.  It can be
populated with plots by right clicking on telemetry items in the
telemetry tab.

The bottom pane has a command line console which shows the commands
sent internally by tview and their responses, and provides an
interactive console to interact with the device using the diagnostic
protocol.

# How position mode works #

The primary control mode for the moteus controller is an integrated
position/velocity controller.  The semantics of the control command
are somewhat unorthodox, so as to be easily amenable to idempotent
commands sent from a higher level controller.  Each command looks
like:

 * Position: The desired position *right now* in revolutions
 * Velocity: The rate at which the desired position changes in
   revolutions / s
 * Maximum torque: Never use more than this amount of torque when controlling
 * Feedforward torque: Give this much extra torque beyond what the
   normal control loop says
 * Stop position: If non-special, never move the desired position away
   from this target.
 * kp scale: Scale the proportional constant by this factor
 * kd scale: Scale the derivative constant by this factor

Additionally, the position may be set as a "special value" (NaN for
floating point and the debug interface, maximal negative for integer
encodings).  In that case, the position selected is "wherever you are
right now".

Some limited amount of preprogrammed constant velocity trajectories
can be emulated using an unset position and the stop position.  In
that case, the sign of the velocity command is ignored, and is instead
selected to point towards the stop position.  If that is the only
command, or that command is repeated indefinitely, it will have the
same effect of causing the controller to move to the stop position at
a constant velocity.

A pure velocity mode can be obtained by setting the kp scale to 0 (or
permanently so by configuring the kp constant to 0).

# Initial Configuration #

There are a few parameters you will likely want to configure early on
in your setup:

* `servopos.position_min` and `servopos.position_max` these define the bounds of motion which the controller will allow when in position control mode.  Attempting to start beyond this region will fault, and if outside the region in operation, no torque will be applied to go further outside.
* `servo.max_current_A` the maximum phase current to apply to the motor.  This can be used to limit the maximum torque that the system is capable of regardless of any command sent.
* `servo.pid_position` the PID parameters for the position control loop.
* `motor.unwrapped_position_scale` any gearbox scaling, a reducing gearbox should be configured with a number smaller than one, e.g. 0.25 for a 4x reduction gearbox.  This affects reported position, speed, and torques.
* `id.id` the CAN-FD id used by this device

A larger set of parameters is documented in the reference manual.

# Upgrading the Firmware #

## Flashing over CAN ##

```
python3 -m moteus.moteus_tool --target 1 --flash path/to/file.elf
```

## Flashing from the debug port ##

If you want to re-flash the firmware using the debugging port, a custom openocd is currently required.  Clone and install from mjbots/openocde

```
sudo apt install autotools-dev automake autogen autoconf libtool libusb-1.0-0-dev
git clone https://github.com/mjbots/openocd
cd openocd.git
./bootstrap
./configure && make && sudo make install
```

Then you can either flash using bazel:

```
tools/bazel test --config=target //fw:flash
```

Or re-flash the same file using:

```
./fw/flash.sh
```

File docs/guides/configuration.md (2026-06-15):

# Configuration

Before using a moteus controller for the first time, it is necessary to configure several key parameters. These parameters define operational limits, control behavior, and configure the system to match your specific application.

## Essential Configuration Parameters

The following parameters should be reviewed and will likely need to configured in a customized way for nearly every application.

### Position Limits

**`servopos.position_min` and `servopos.position_max`**

These define the bounds of motion which the controller will allow when in position control mode. Attempting to start beyond this region will fault, and if outside the region during operation, no torque will be applied to move further outside these limits.  If they are unwanted, `nan` should be used to disable them.

### Current Limits

**`servo.max_current_A`**

The maximum phase current to apply to the motor. This can be used to limit the maximum torque that the system is capable of producing, regardless of any command sent. Set this based on your motor's peak current rating and thermal capabilities.

### Velocity Limits

**`servo.max_velocity`**

Limits the maximum speed the motor is permitted to achieve before no torque is produced. This acts as a safety limit to prevent excessive speeds that could damage the motor or mechanical system.

**`servo.default_velocity_limit` / `servo.default_accel_limit`**

Controls how fast the motor can accelerate and spin in order to reach position and velocity targets. Bare boards ship with these unset, while development kits ship with human-eye pleasing values. Adjust these to match your application's performance requirements.

### Gearbox Scaling

**`motor_position.rotor_to_output_ratio`**

A gearbox scaling factor. A reducing gearbox should be configured with a number smaller than one (e.g., 0.25 for a 4x reduction gearbox). This affects reported position, speed, and torques, scaling them to represent the output shaft values rather than motor shaft values.

### Device Identification

**`id.id`**

The CAN-FD ID used by this device. Each controller on the bus must have a unique ID. Valid IDs range from 1 to 126.  If you set this to a value other than 1, be aware that unless your tview and controller firmware are newer than late 2025, you will need to restart tview with:

```
python -m moteus_gui.tview -t N
```

Where N is the new ID, in order to issue a `conf write` to save the
parameters.

### PID Parameters

**`servo.pid_position`**

The PID parameters for the position control loop. It will be necessary to tune these, it isn't hard, although it must be done after calibration is performed. You'll get to the [PID Tuning guide](../guides/pid-tuning.md) after completing the calibration process.

## Saving parameters

All parameters (including the ID) are temporarily stored in volatile memory that will be discarded after a power cycle.  To save those parameters to persistent storage, it is necessary to type:

```
conf write
```

Into the diagnostic console of tview.

## Additional Configuration

A larger set of parameters is documented in the [Configuration Parameters Reference](../reference/configuration.md), covering advanced features such as:

- Motor electrical characteristics
- Encoder configuration
- Temperature limits
- Communication settings
- Advanced control parameters

## Next Steps

After configuring these essential parameters, you should familiarize yourself with the encoder system and position feedback:

- [Encoder Overview](encoder-overview.md)

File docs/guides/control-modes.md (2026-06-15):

# Control Modes

The moteus controller offers flexible control modes to suit different robotics applications. By adjusting control gains and command parameters, you can optimize the controller for various use cases—from precise positioning and velocity control to high-bandwidth torque applications. This guide covers the recommended configurations for common control scenarios.

## Understanding Position Mode

The primary control mode for the moteus controller is an integrated position/velocity controller. The semantics of the control command are somewhat unorthodox, so as to be easily amenable to idempotent commands sent from a higher level controller. Each command includes the following parameters:

- **Position**: The desired position in revolutions
- **Velocity**: The rate at which the desired position changes in revolutions/s
- **Maximum torque**: Never use more than this amount of torque when controlling
- **Feedforward torque**: Give this much extra torque beyond what the normal control loop says
- **Stop position**: If non-special, never move the desired position away from this target
- **kp scale**: Scale the proportional constant by this factor
- **kd scale**: Scale the derivative constant by this factor
- **ilimit scale**: Scale the integrative limit by this factor
- **Velocity limit override**: If non-special, override the configured velocity limit, which constrains how quickly the target position is reached
- **Acceleration limit override**: If non-special, override the configured acceleration limit, which constrains how quickly the target position is reached

Additionally, the position may be set as a "special value" (NaN for floating point and the debug interface, maximal negative for integer encodings). In that case, the position selected is "wherever you are right now".

A pure velocity mode can be obtained by setting the kp scale to 0 (or permanently so by configuring the kp constant to 0). In this case, using the `servo.max_position_slip` configurable parameter may be valuable as per the velocity control section below.

## Constant Acceleration Trajectories

Velocity and acceleration limits can be configured either globally, or
on a per-command basis which will cause moteus to internally generate
continuous acceleration limited trajectories to reach the given
position and velocity.  Once the trajectory is complete, the command
velocity is continued indefinitely.

=== "Diagnostic Protocol"

    ```
    # Move to position 1 then stop.  Accelerate/decelerate at 2Hz/s
    # and use a maximum velocity of 0.5Hz.
    d pos 1 0 nan a2 v0.5
    ```

=== "Python"

    ```python
    await controller.set_position(
        position=1,
        velocity=0,
        accel_limit=2,
        velocity_limit=0.5,
    )
    ```

=== "C++"

    ```cpp
    mjbots::moteus::Controller::Options options;
    options.position_format.accel_limit = mjbots::moteus::kFloat;
    options.position_format.velocity_limit = mjbots::moteus::kFloat;

    mjbots::moteus::Controller controller(options);

    mjbots::moteus::PositionMode::Command cmd;
    cmd.position = 1.0;
    cmd.velocity = 0.0;
    cmd.accel_limit = 2.0;
    cmd_velocity_limit = 0.5;

    auto result = controller.SetPosition(cmd);
    ```

Default values for acceleration and velocity limits can also be set in
configuration.

* `servo.default_accel_limit`
* `servo.default_velocity_limit`

## Velocity Control

To implement a velocity controller, each command should have the
"position" set to NaN (or equivalent integral encoding).  It is
recommended to configure `servo.max_position_slip` to a finite value
greater than or equal to 0 ([reference](../reference/configuration.md#servomax_position_slip)).
When it is larger, more external disturbances will be rejected, but
the controller will also "catch up" when the magnitude of external
disturbances is decreased.

**Example:**

=== "Diagnostic Protocol"

    ```
    d pos nan 2 nan
    ```

=== "Python"

    ```python
    await controller.set_position(
        position=math.nan,  # NaN for velocity mode
        velocity=2.0,       # 2 revolutions/second
        query=True
    )
    ```

=== "C++"

    ```cpp
    mjbots::moteus::PositionMode::Command cmd;
    cmd.position = std::numeric_limits<double>::quiet_NaN();
    cmd.velocity = 2.0;  // 2 revolutions/second

    auto result = controller.SetPosition(cmd);
    ```

## Torque Control

For a pure torque control application, the PID gains of the position control loop must be set to 0.  One way to accomplish that is by sending the `kp_scale`, `kd_scale`, and `ilimit_scale` values to 0.

=== "Diagnostic Protocol"

    ```
    # Command a torque of 0.1 Nm
    d pos nan 0 nan p0 d0 i0 f0.1
    ```

=== "Python"

    ```python
    await controller.set_position(
        position=math.nan,
        velocity=0,
        kp_scale=0.0,
        kd_scale=0.0,
        ilimit_scale=0.0,
        feedforward_torque=0.1,
    )
    ```

=== "C++"

    ```cpp
    mjbots::moteus::Controller::Options options;
    options.position_format.kp_scale = mjbots::moteus::kFloat;
    options.position_format.kd_scale = mjbots::moteus::kFloat;
    options.position_format.ilimit_scale = mjbots::moteus::kFloat;
    options.position_format.feedforward_torque = mjbots::moteus::kFloat;

    mjbots::moteus::Controller controller(options);

    mjbots::moteus::PositionMode::Command cmd;
    cmd.position = std::numeric_limits<double>::quiet_NaN();
    cmd.velocity = 0.0;
    cmd.kp_scale = 0.0;
    cmd.kd_scale = 0.0;
    cmd.ilimit_scale = 0.0;
    cmd.feedforward_torque = 0.1;

    auto result = controller.SetPosition(cmd);
    ```

**Caveat**: Using external torque control will be much lower
bandwidth than using the internal position controller of moteus (~15x
lower bandwidth if maximal CAN-FD update rate is achieved).  Thus, a
system will usually perform better if as much of the desired control
law as possible is formulated in terms of the built in position
controller.

If the system will never perform anything *but* torque control, then the PID gains can be set to 0 in configuration.

* `servo.pid_position.kp`
* `servo.pid_position.kd`
* `servo.pid_position.ilimit`

## Jerk Limited Trajectories

moteus only supports acceleration limited internal trajectories.  To
approximate a constant jerk trajectory, the host processor should send
a sequence of piecewise linear constant velocity trajectories which
approximate the desired one.  This would be done by sending commands
consisting of at least a position and velocity at some moderate to
high rate while disabling the internal velocity and acceleration
limits.

## Low Speed or Precise Positioning

For either operation at very low speeds, or when precise positioning
performance is desired, it is recommended to configure a non-zero `ki`
and `ilimit` term in the position controller
([reference](../reference/configuration.md#servopid_position)).  This will compensate for cogging
torque (at the expense of overall torque bandwidth).  It may also be
beneficial to select a higher value for calibration bandwidth.

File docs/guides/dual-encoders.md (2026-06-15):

# Dual Encoder Configuration

Often moteus is used in applications where a gearbox or other reducer is used between the rotor and the final plant.  In those situations it can be valuable to have a secondary encoder measuring the output of the reducer:

**Absolute positioning**: With only an encoder on the rotor, it is not possible to know absolutely where the output is.

**Improved accuracy or sensing performance**: The onboard encoder included with moteus is sufficient for commutation for nearly all motors, however some applications may require lower position or velocity sensing noise or higher resolution in order to achieve accurate very slow movements, or very accurate positioning.

This section will cover how to set up several common dual encoder configurations.

## Important factors when configuring dual encoders

1. **Sign match**: moteus requires that the sign of all encoders match.  Those must be configured manually in `motor_position.sources.X.sign`.  To verify the signs are correct, plot `motor_position.sources.X.filtered_value` for all configured encoders, spin the system by hand, and verify that all plots move in the same direction.

2. **Offset match**: If the absolute values of multiple encoders must be related, such as for a disambiguation configuration, then the offsets must be matched so that the encoders read 0 at the same time.  These offsets must be manually configured in `motor_position.sources.X.offset`.  To verify they are correct, plot `motor_position.sources.X.filtered_value` for all configured encoders, spin the system by hand to the zero point, and verify that all encoders read 0.

## Onboard + 8x reducer + MA600 on-axis - Disambiguation

In this configuration, the rotor is sensed with the moteus onboard encoder and the output is sensed with an MA600 on-axis encoder.  Assuming low backlash, the output positioning is performed from the onboard encoder and the output encoder is only used for disambiguation.  This results in the best performance since the effective resolution of the onboard encoder is multiplied by the gear reduction and will be much better than the MA600 on the output.

The MA600 is attached to the aux2 port on one of the moteus-c1 [(c1 pinout)](../reference/pinouts.md#moteus-c1), moteus-n1 [(n1 pinout)](../reference/pinouts.md#moteus-n1), or moteus-x1 [(x1 pinout)](../reference/pinouts.md#moteus-x1).

This pinout is the one accomplished if using the cable included with the [mjbots MA600 breakout board](https://mjbots.com/products/ma600-breakout).

If starting from a factory default configuration, first, configure the
aux2 port:

```
aux2.pins.0.mode 1  # spi
aux2.pins.1.mode 1  # spi
aux2.pins.2.mode 1  # spi
aux2.pins.3.mode 2  # spi_cs
aux2.spi.mode 5     # ma600
aux2.spi.rate_hz 6000000
```

Then, configure motor_position:

```
motor_position.sources.1.aux_number 2
motor_position.sources.1.type 1
motor_position.sources.1.cpr 65536
motor_position.sources.1.reference 1  # output
motor_position.rotor_to_output_ratio 0.125
motor_position.output.reference_source 1
```

The sign and offset of the MA600 will need to be matched to the onboard encoder as per [the above section](#match).

## Onboard + 10x reducer + AksIM-2 on output

In this configuration, the onboard encoder is used to sense the rotor, and an AksIM-2 encoder from RLS is used on the output.  The AksIM-2 has much better accuracy and noise performance than the onboard on-axis encoder, and thus this configuration could be used for applications where either very accurate positioning is required, or very precise low speeds are required.

The AksIM-2 is attached to the GH-6 RS422 connector on a moteus-n1 [(n1 pinout)](../reference/pinouts.md#moteus-n1) or moteus-x1 [(x1 pinout)](../reference/pinouts.md#moteus-x1).

moteus is compatible with AksIM-2 encoders configured as follows:

- **Communication Interface**: SF - Asynchronous Serial, RS422, 5V
- **Communication Protocol Variant**: F - 1000 kbps
- **Resolution**: <= 19B, no multiturn support

If starting from a factory default configuration, first configure the aux1 port.

```
aux1.pins.3.mode 3 # uart
aux1.pins.4.mode 3 # uart
aux1.uart.mode 1 # aksim2
aux1.uart.baud_rate 1000000
aux1.rs422 1
```

Then configure motor_position:

```
motor_position.rotor_to_output_ratio 0.1
motor_position.sources.1.aux_number 1
motor_position.sources.1.type 2          # uart
motor_position.sources.1.cpr 4194304     # used by moteus for all AksIM-2
motor_position.sources.1.reference 1     # output
motor_position.output.source 1
```

The sign and offset of the AksIM-2 will need to be matched to the onboard encoder as per [the above section](#match).

## Hall + 10x reducer + Off axis MA600

In this configuration, hall effect encoders are used to sense commutation and an MA600 is used in conjuction with a diametrically magnetized ring magnet for output positioning.  It is designed as one of the lowest cost options for a hollow axis actuator with a gear reduction, as the off-axis MA600 has minimally acceptable performance as does the hall effect sensors.

The MA600 is connected to AUX1 on a moteus-n1 [(n1 pinout)](../reference/pinouts.md#moteus-n1) or moteus-x1 [(x1 pinout)](../reference/pinouts.md#moteus-x1) and the hall effect sensors are connected to AUX2.

First, we will configure the hall effect sensors and calibrate them.

```
aux2.pins.0.mode 6  # hall
aux2.pins.0.pull 1  # pull_up
aux2.pins.1.mode 6  # hall
aux2.pins.1.pull 1  # pull_up
aux2.pins.2.mode 6  # hall
aux2.pins.2.pull 1  # pull_up
aux2.hall.enabled 1
motor_position.rotor_to_output_ratio 0.1
motor_position.sources.0.aux_number 2
motor_position.sources.0.type 4  # hall
```

Then, the hall effect sensors are calibrated:

```
python -m moteus.moteus_tool -t 1 --calibrate --cal-motor-poles 30
```

Now we will configure the MA600.

```
aux1.pins.0.mode 1  # spi
aux1.pins.1.mode 1  # spi
aux1.pins.2.mode 1  # spi
aux1.pins.3.mode 2  # spi_cs
aux1.spi.mode 5     # ma600
aux1.spi_rate_hz 6000000
motor_position.sources.1.aux_number 1
motor_position.sources.1.type 1  # spi
motor_position.sources.1.cpr 65536
motor_position.sources.1.reference 1  # output
```

Then, before configuring the MA600 to be used for output, match the sign of the MA600 and hall effects according to [the procedure here](#match).

For an off-axis MA600, BCT tuning should be performed, and non-linear compensation may be performed.

```
moteus$ ./utils/measure_ma732_bct.py
```

To peform non-linear compensation, you can use:

```
moteus$ ./utils/compensate_encoder.py
```

Finally, the MA600 can be configured as the output source:

```
motor_position.output.source 1
```

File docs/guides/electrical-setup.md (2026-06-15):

# Electrical Setup

To use moteus without damage, proper care must be paid to the electrical connections and configuration.  This section describes how.

## Electrical Connections

**Motor**: Phase wires for the motor should be soldered to the pads labeled A, B, and C. The order does not matter. The location of the pads varies between controllers.  An inline connector, like an MR30, MR60, or bullet connectors can be used if repeated disconnection is desired.

**Power**: Power is provided via either the onboard XT30 connector, or on board-mountable moteus controllers, via the power pads that are interleaved with the A, B, and C phase pads.  The power input is *NOT* protected against reverse polarity.  Polarity should be triple checked before applying power, or irreversible damage may result.  XT30 connectors have a clear '+' and '-' marking on them which can be used to identify the positive and negative input.

If you are unsure, pinout diagrams for all controllers can be found here: [Pinout diagrams](../reference/pinouts.md)

!!! note "Hot plugging"
    It is important to *never* hot plug an XT30 connector.  The XT30 connector (and all connectors which are not anti-spark), should be connected *before* power is applied.  If you see or hear a spark, you have applied power in the wrong order.  See the below section on inrush current management.

## Soldering and cable construction techniques

moteus controllers can be damaged when improper techniques are used to attach wires to them, or improper techniques are used to construct power cables.

### Phase Wire Soldering

The connections between moteus and the motor under control must be high quality.  Poor quality solder joints can cause intermittent changes in resistance, sparking, and high voltage transients.  High quality solder joints require:

* Sufficient flux to clean oxides off of the wire and the via
* Sufficient temperature so that the entire wire and via is hot enough for the solder to wet all surfaces

For the former, it is often necessary to add copious amounts of additional flux in addition to the rosin core inside many solders.  For the latter, a high power soldering iron, with a fat tip, and what seems like a long time may be necessary.  The temperature is definitely insufficient if solder touched to any part of the via or wire does not melt and wick instantly.  Usually a small amount of solder is placed between the tip and wire to act as a heat transfer agent.  Then the iron rests on the via and wire for between 5-30s until it looks like the initial solder has wicked fully into the via.  Then additional solder can be added until it forms a clean smooth fillet around the entire via wicking up to the wire.

When complete, the back side of the hole can be examined, and if successful, solder will have wicked partially down out of the via onto the other side forming a clean, smooth fillet there as well.

A demonstration of this can be found in the following video: [https://www.youtube.com/watch?v=mZ9w_TaWmjQ](https://www.youtube.com/watch?v=mZ9w_TaWmjQ)

{{ youtube("mZ9w_TaWmjQ") }}

### Power Cable Construction

When constructing power cables using XT30 connectors, it is critical that solder joints be sound, otherwise intermittent connectivity can result.  This can cause sparking and high voltage transients.  The soldering principles are the same as in the phase wire soldering section above.

A demonstration of XT30 soldering can be found in the following video:
[https://www.youtube.com/watch?v=f6WtDFWuxuQ](https://www.youtube.com/watch?v=f6WtDFWuxuQ)

{{ youtube("f6WtDFWuxuQ") }}

### Power Connectorization

For moteus to operate without damage, the XT30 connectors used to transmit power must make a solid connection that is non-intermittent.  As with poor soldering, an intermittent connection can cause inductive spikes, which will destroy components on the controller.

When connectors are functional, moderate insertion force should be required and the connectors should not "wiggle" much after insertion.

The XT30 is not rated for any significant amount of mechanical force when mated.  For any application where cables may flex, strain relief should be used such that no force is applied to the connector.  The connector may be damaged if a system goes "out of control" even in one instance, although milder mechanical stress may cause accelerated fatigue and failure.

If sparks are observed, that is *definitely* a problem and the system should be powered off until the connectors can be replaced and mitigations made for what led to that event.

Genuine AMASS connectors are rated for 1000 insertions assuming no other mechanical damage, however off-brand connectors may have worse tolerances and may not make a reliable connection for even one insertion.

### Long daisy chains

When connecting more than 3 moteus controllers or servos in a system on a single power or CAN chain, additional factors should be considered.

1. It is recommended to use T-spliced power instead of using the daisy chained power connectors for chains greater than 3 units.  Small connector mis-seating or micro-arcing will cause magnified effects with long chains of controllers.

2. CAN bus electrical performance can be a limiting factor.  To operate at the default 5Mbps, you will need to ensure that CAN wires are twisted, all crimps are high quality, and that termination is installed.  Split termination may be required, where two 60 ohm resistors are connected in series with a small filter capacitor connected between the center tap of the resistors and ground.  A 4.7nF capacitor is recommended.  If that is insufficient, BRS can be disabled to operate only at 1Mbps.  With `moteus_tool` or `tview`, the `--can-disable-brs` flag can be used.

mjbots sells a CAN terminator that can be used for this purpose: [https://mjbots.com/products/jst-ph3-can-fd-terminator](https://mjbots.com/products/jst-ph3-can-fd-terminator)

## Inrush current management

moteus controllers have large DC bulk capacitance with low ESR, this is how they can achieve their small form factor.  As a result, care must be taken when applying power.  If a connector is "hot-plugged" extremely large transient currents can develop which may damage the moteus or other components in the system.  These challenges are magnified when more than one moteus controller is attached to the same power bus.

Potential solutions:

**Power Supply**: If a wall power supply is used, it can be relied upon to provide a "soft start" functionality.  Ensure that all moteus controllers are attached to the power supply *before* enabling the supply by turning it on or plugging it into a wall.

**Anti-spark connectors**: There exist anti-spark connectors like the XT90-S, which have a power resistor built in which makes contact before main power is applied.  These can be used, but have several drawbacks:

1. The proper order of connection must always be obeyed.  Unless the XT90-S is connected *last*, then inrush transients may result.
2. If the power rating on the built-in resistor is not respected, it will silently fail, resulting in no pre-charge protection at all.

**Active pre-charge circuits**: mjbots sells the [mjpower-ss](https://mjbots.com/products/mjpower-ss) and [power_dist](https://mjbots.com/products/mjbots-power-dist-r4-5b), both of which have the primary function of gradually precharging capacitive loads.  Other active pre-charge systems may also be viable.

## Regenerative braking safety

moteus can be commanded to sharply decelerate loads, either directly in response to commands, or due to external disturbances.  When braking a load, moteus by default applies the generated power to the input DC bus.

If there is nowhere for this power to go, this can cause problems.  The voltage can increase without bound, which in mild cases will cause the CAN transceiver on all devices connected to the bus to fail, and in severe cases can explode the main FETs or other components on the board.

Here's what you should know about the facilities moteus has to deal with this, and what you can do to make your design safer.

### Software protections

moteus has several configurable mechanisms to limit regenerative voltage rise.  For full tuning details, see [Troubleshooting Overvoltage Fault 34](../troubleshooting/overvoltage-fault-34.md).

**Acceleration limits**: Setting `servo.default_accel_limit` (or per-command `accel_limit`) controls how quickly braking torque is applied.  This is the most direct way to limit the rate of regenerative power injection.

**Regen power limiting**: Setting `servo.max_regen_power_W` limits how much power is allowed to flow back to the bus during braking.  Excess energy is pre-emptively dissipated in the motor windings via d-axis current injection.  For a supply that cannot absorb any regenerative energy, set this to a small number like `10` or even `0`.

**Flux braking**: When bus voltage rises above `servo.max_voltage - servo.flux_brake_margin_voltage`, moteus dissipates energy in the motor windings to resist further voltage rise.  This is controlled by `servo.flux_brake_margin_voltage` and `servo.flux_brake_resistance_ohm`.

### Hardware design considerations

The following design considerations can be used to minimize the risk of damage to hardware in the event of overvoltage.  These are not a substitute for validation in progressively more demanding situations, but they can help you start off in a good place.

- *Tightly scope the over-voltage fault / flux braking*: The configuration parameter `servo.max_voltage` can be lowered for all devices on the bus.  This will both cause a fault if the voltage exceeds this value and in conjunction with `servo.flux_brake_margin_voltage`, select the point at which moteus will attempt to dissipate energy to prevent an overvoltage scenario.  It is recommended to set this to no less than 5V above the maximum expected supply voltage.

- *Power from a battery, not a PSU*: When not charged, batteries are capable of sinking current to minimize over-voltage transients.  However, if the battery is fully charged, most battery management systems drastically reduce the allowable charging current.  Thus, a battery is only useful as a mitigation if it is never charged above say 75 or 80% state of charge.

- *Decrease overall system voltage*: If you run the moteus controller with say a 10S battery, the peak input voltage can be as high as 42V.  That does not leave very much margin for regenerative loads.  For applications that experience sharp regenerative loads and do not have a battery capable of charging always attached, it is recommended not to exceed 8S (33.6V peak).

- *Use a supply which can sink as well as source*: Powering from an inexpensive lab supply is the most dangerous, as they typically have no ability to sink current, only source it.  A "two quadrant" supply is the necessary device.

## Next Steps

After completing electrical connections, proceed to [software installation and configuration](software-installation.md) to begin using your moteus controller.

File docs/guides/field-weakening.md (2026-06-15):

# Field Weakening

## Background

moteus controllers are used to operate permanent magnet synchronous motors (PMSM).  In normal operation, the maximum no-load speed that can be achieved by a PMSM is determined by:

```
max_speed_hz = Kv * supply_voltage / 60
```

With moteus, there are two further constants that are multiplied in, the space vector modulation constant, and the maximum modulation factor constant.  As of 2026, these combine to roughly:

```
k_svpwm * k_maxmod ~= 0.8
max_speed_hz = k_svpwm * k_maxmod * Kv * supply_voltage / 60
```

This limit occurs because the controller can only apply torque when the supply voltage is greater than the back-EMF generated by the motor while it is in motion.  It is possible to apply current in the non-torque generating axis (the D axis) to reduce the effective back-EMF constant and thus increase the effective Kv constant.  This effect is called "field weakening".  The magnitude of this effect depends upon motor construction.  Typically, interior permanent magnet synchronous motors (IPMSM) are capable of relatively large amounts of field weakening at moderate power expenditure.  Most hobby and low-cost brushless motors are surface permanent magnet synchronous motors (SPMSM) for which field weakening is sometimes possible at reasonable power budget and sometimes not.

moteus has support for operating in the field weakening regime and thus extending the maximum achievable speed a motor can achieve for a given supply voltage.  This has several caveats:

- **Power**: The power required to operate a motor will be the same or larger when field weakening is enabled.  When field weakening is used, additional power will start to be used slightly before the no-load speed so that maximum torque can be achieved.  At higher speeds, the power consumed by the supply and dissipated as thermal energy in the motor and controller can be very large.  The amount used is also proportional to the maximum configured current, so if the full amount is not required for your application, lowering `servo.max_current_A` may be helpful.
- **Calibration**: Field weakening relies on the specific value of the D axis inductance.  For many motors, this value can change significantly at different values of D axis current.  In order to operate stably, moteus requires a longer calibration step to measure this D axis inductance saturation scale effect.
- **Stability**: For some motors, moteus must be calibrated at a higher `--cal-bw-hz` to operate at a speed in the field weakening regime than would be necessary if the supply voltage were high enough to not require field weakening.  Calibrating at a higher `--cal-bw-hz` will result in increased audible noise at all speeds.
- **Hardware Limits**: Even when field weakening is enabled, moteus will restrict the maximum speed to be no more than what could be achieved if the used moteus controller was supplied with its maximum rated input voltage.  Thus if you are already operating your controller near the maximum rated board voltage, there may be minimal or no gains in speed achievable through field weakening.

The [moteus performance analysis tool](https://mjbots.github.io/moteus/mpat.html) can be used to estimate the power required and performance when field weakening is enabled or disabled for a given system.

## Usage

Using field weakening with moteus requires calibration procedures and configuration values to be set.  Additionally, there are diagnostic values which can be monitored.

### Calibration

When calibrating, it is recommended to perform the D axis inductance scale procedure.

```
python -m moteus.moteus_tool -t 1 --calibrate --cal-measure-ld-saturation
```

This will require several minutes of operation and may require active cooling of the motor or controller in order to succeed.

The calibrated `L_d` scale will be nearly the same for all copies of a single motor design, so this parameter can be copied from controller to controller so that the calibration only needs to occur once across multiple instances.

```
servo.inductance_d_scale
```

### Configuration

To enable field weakening operation, use this configuration:

```
servo.fw.enable 1
servo.bemf_feedforward 1
```

`servo.bemf_feedforward` should be set to 1 when field weakening is used so that the controller can properly anticipate the back-EMF voltage and maintain stable operation at high speeds.

### Monitoring

When in operation, there are some diagnostic values that can be monitored:

`servo_stats.motor_base_velocity`: This is the speed at which field weakening begins.  Above this speed, additional power will be applied to the motor, increasing with speed, to enable operation above the no-load speed.

`servo_stats.motor_max_velocity`: This is the maximum speed moteus will permit.  Note that this is not a continuous rated speed, as temperature of the board or motor may rapidly exceed configured limits when operating at large levels of field weakening.

`servo_stats.fw.id_A`: The amount of D axis current currently being used to decrease the back EMF constant.

## Limitations

- **Board maximum voltage**: moteus limits field weakening speed such that the back EMF produced by the motor never exceeds `servo.max_voltage` minus an appropriate margin
- **Maximum D axis current**: `servo.fw.max_current_ratio` is multiplied by `servo.max_current_A` to determine the maximum D axis current that can be used for field weakening
- **Thermal performance**: Field weakening operates by applying *more* power to the motor.  This means it will increase in temperature faster, reducing thermal performance.

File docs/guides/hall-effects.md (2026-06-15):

# Motor with Hall Effect Sensors

Many motors include hall effect sensors used to provide commutation information to motor controllers.  moteus is able to use hall effect sensors for both commutation and output positioning.  First, some caveats:

**They may not be needed**: Just because a motor has hall effect sensors built in, does not mean you need to use them.  If you can use the on-axis magnetic encoder integrated into moteus by mounting moteus appropriately relative to the rotor, that will always give better results than using hall effect encoders.

**You will likely need additional hardware**: Most configurations with hall effects will require additional filtering capacitors, placed near moteus, between each signal line and ground.  1nF is a recommended starting point.  They can be added either in the wire harness, or on unpopulated 0402 pads on the moteus-c1, moteus-n1, and moteus-x1.

**Hall effect sensors used for output positioning have very poor low velocity performance**: While hall effect sensors are minimally useful for commutation and higher speed output operation, they will provide poor performance when used as an output encoder at low speeds.  That means many position control applications, which are inherently often at low speed, will give poor results.

**moteus-r4 cannot easily drive many hall effect sensors**: moteus-r4 specifically has only 3.3V supply for external devices, whereas most hall effect encoders require 5V.  Further, the only means of connecting hall effect sensors to moteus-r4 are using unpopulated pads on the back of the board, and *not* using the onboard encoder.  Other moteus products do not have these specification limitations regarding supply voltage and connectors.

If using hall effects for commutation or output positioning is still desired, the below configurations can get you started.

## aux2 configuration ##

This configuration uses hall effect sensors connected to the aux2 GH7
connector for both commutation and output positioning.

moteus-c1 [(c1 pinout)](../reference/pinouts.md#moteus-c1), moteus-n1 [(n1 pinout)](../reference/pinouts.md#moteus-n1), and moteus-x1 [(x1 pinout)](../reference/pinouts.md#moteus-x1) all have an aux2 GH7 connector that can provide 5V output and has 5V tolerant IO pins.  The typical wiring diagram looks like the below, although the hall connector is "nominal" as there is no real standard:

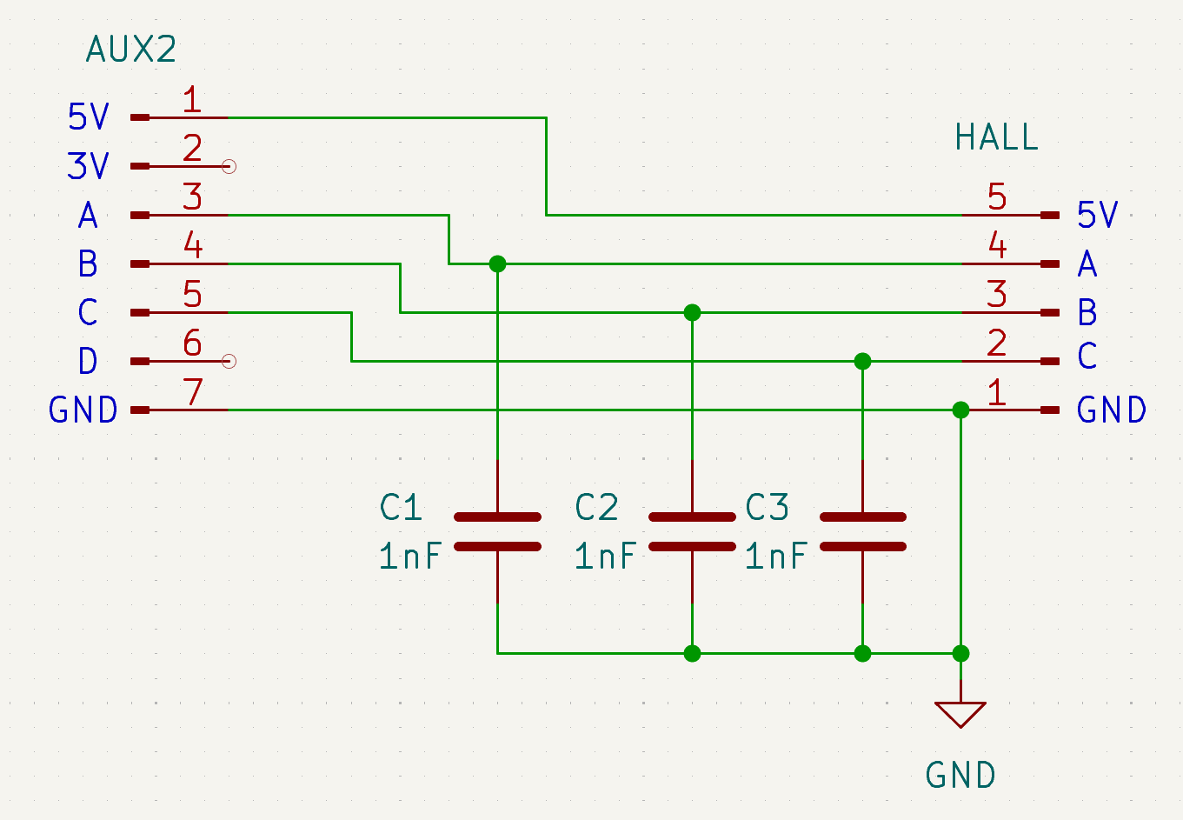
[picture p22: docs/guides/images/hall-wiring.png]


As mentioned above, either 1nF capacitors should be installed in the harness between each signal line and ground, or installed on the appropriate unpopulated pads on the board.

The following aux2 configuration parameters should be set.

```
aux2.pins.0.mode 6  # hall
aux2.pins.0.pull 1  # pull_up
aux2.pins.1.mode 6  # hall
aux2.pins.1.pull 1  # pull_up
aux2.pins.2.mode 6  # hall
aux2.pins.2.pull 1  # pull_up
aux2.hall.enabled 1
```

Then motor_position is configured as follows:

```
motor_position.sources.0.aux_number 2
motor_position.sources.0.type 4  # hall
```

Finally, when calibrating, the number of poles is required to be
specified.

```
python -m moteus.moteus_tool -t 1 --calibrate --cal-motor-poles 30
```

## Advanced: Dual Encoder Setup

A more performant configuration may use the hall effect sensors for commutation and a different encoder measuring the output position.  That is not directly described here, but you can look at the [Dual Encoders](dual-encoders.md) guide as well as the [encoder reference](../reference/encoders.md) to understand how to configure it.

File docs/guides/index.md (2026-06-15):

# Using moteus

Step-by-step guides for setting up and using moteus.

- [Mechanical Setup](mechanical-setup.md) - Physical installation
- [Electrical Setup](electrical-setup.md) - Wiring and power connections
- [Software Installation](software-installation.md) - Installing client software
- [Configuration](configuration.md) - Basic configuration
- [Encoder Overview](encoder-overview.md) - Understanding encoder options
- [Calibration](calibration.md) - Motor calibration procedure
- [PID Tuning](pid-tuning.md) - Tuning position and velocity control
- [Control Modes](control-modes.md) - Position, velocity, and torque modes

## Advanced Configuration

- [Motor with Hall Effects](hall-effects.md) - Using hall effect sensors
- [Dual Encoders](dual-encoders.md) - Separate motor and output encoders

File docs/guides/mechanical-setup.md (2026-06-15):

# Mechanical Setup

To use the onboard on-axis encoder integrated with moteus, the controller must be mounted with care to ensure proper alignment and ongoing registration.

## Mechanical Mounting

If using the default onboard encoder, the following steps must be taken:

1. A diametrically magnetized sense magnet should be attached to the rotor (*NOT* the output of any reducer or linkage). The fastening must be rigid, allowing no slip. Adhesive is generally required, cyanoacrylate or epoxy can be used.
2. The moteus controller must be mounted so that the encoder is (a) centered laterally on the sense magnet and (b) has an air-gap of approximately 2mm. This mount must be rigid and allow no slip.

!!! note "moteus-r4 mounting"
    Unlike other moteus controllers, the moteus-r4 encoder is *not* centered under the bolt pattern, check the [2D CAD for details](https://github.com/mjbots/moteus/blob/main/hw/controller/r4.5/20210124-moteus-controller-r45-mechanical.pdf).

!!! note "3D printed mounts"
    If using 3D printed mounts, care should be taken to ensure the mount does not warp.  PLA and other low temperature filaments will warp under load at room temperature, and will do so even more when exposed to thermal heating like from a motor controller.  It is recommended to use PETG, PC, or a filament designed to not warp at the operating temperature you intend.

## Additional Considerations

There are additional considerations when mounting, some mostly common sense, and some unique to moteus.

### Protection from debris and stray conductors

It is advisable to mechanically shield moteus controllers from the environment during operation to prevent contact with stray conductors, dirt, or debris.  Contact with any of these things while the system is energized can result in failure.

Similarly, manipulating or working on the system while it is energized should be avoided.

### moteus-n1 light sensitivity

moteus-n1 has a voltage regulator which is light sensitive and will fail when exposed to sunlight.  The enclosure used to house the system should be opaque.  If for some reason an enclosure can not be used, opaque expoxy can be placed over the voltage regulator IC.

moteus-c1, moteus-r4 and moteus-x1 have no light sensitivity considerations to take into account.

## Next Steps

Once mechanical mounting is complete, proceed to [Electrical Setup](electrical-setup.md) to connect the motor phase wires and power.

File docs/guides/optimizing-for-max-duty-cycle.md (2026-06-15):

# Optimizing for maximum duty cycle

## Background

In some cases, it is important that moteus be able to achieve the maximum possible speed on a given motor without resorting to field weakening.  The controller is limited in how much of the supply voltage it can apply to the motor.  By definition the multiple that it can supply is less than 1.  This multiple is constrained by moteus's requirement to be able to sense the current flowing to the motor in order to perform field oriented control. Two factors bound this constraint:

1. The current can only be sensed when the "low" side MOSFET is switched on.  Thus, the low-side MOSFET must be on long enough for ADC to trigger and complete its sampling process.
2. The input to the ADC is a current sense amplifier (CSA) onboad moteus.  This amplifier has a gain dependent settling time that must be respected.  This settling time must complete *before* the ADC sampling process starts.

## Tuning parameters

To maximize the available duty cycle, there are two parameters that can be controlled.

1. `servo.pwm_rate_hz`: The lower the PWM rate, the higher the available duty cycle.  Setting it to the minimum of 15000 Hz is the limit.  Lower PWM rates decrease the control update rate and decrease the peak power the board can support.

2. `drv8323.csa_gain`: The current sense amplifier gain, which can be one of [5, 10, 20, 40].  The default is 20.  Lowering this to 10 gives the maximum duty cycle benefit at the expense of increased current sense noise.  This will result in more audible noise from the system and lower available torque control bandwidth.

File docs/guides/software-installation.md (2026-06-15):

# Software Installation

This guide covers installing the software tools needed to communicate with and configure your moteus controller.

## Installing moteus_gui

The moteus_gui package provides essential tools including `tview` (telemetry viewer) and `moteus_tool` (configuration utility). Installation varies slightly by platform.

=== "Linux"

    ```bash
    python -m pip install moteus-gui
    ```

    **Note**: On Linux, you may need to use either a [virtual environment](https://docs.python.org/3/library/venv.html#creating-virtual-environments) or the `--break-system-packages` option.

    **fdcanusb udev rules**: If using the fdcanusb or mjcanfd-usb-1x adapter, you may need to set up udev rules so regular users can access the device. Follow the instructions at: [https://github.com/mjbots/fdcanusb/blob/master/70-fdcanusb.rules](https://github.com/mjbots/fdcanusb/blob/master/70-fdcanusb.rules)

=== "Windows"

    ```bash
    python -m pip install moteus-gui
    ```

    **Note**: On some older Windows installations, you need to invoke python as `python3`, not `python`.

=== "macOS"

    ```bash
    python -m pip install moteus-gui
    ```

=== "Raspberry Pi (cmdline only)"

    ```bash
    python -m venv moteus-venv --system-site-packages
    ./moteus-venv/bin/pip install moteus

    ```

    **Note**: For complete Raspberry Pi setup instructions including GUI and hardware configuration, see [Raspberry Pi Setup](../platforms/raspberry-pi.md).

## Running tview

tview is the primary tool for configuring and inspecting the state of your moteus controller. Launch it with:

```bash
python3 -m moteus_gui.tview
```

**Alternative**: Your pip installation may have added a `tview` script to your PATH, which you can use instead.

## Understanding tview

tview has three main panes: left, right, and bottom.

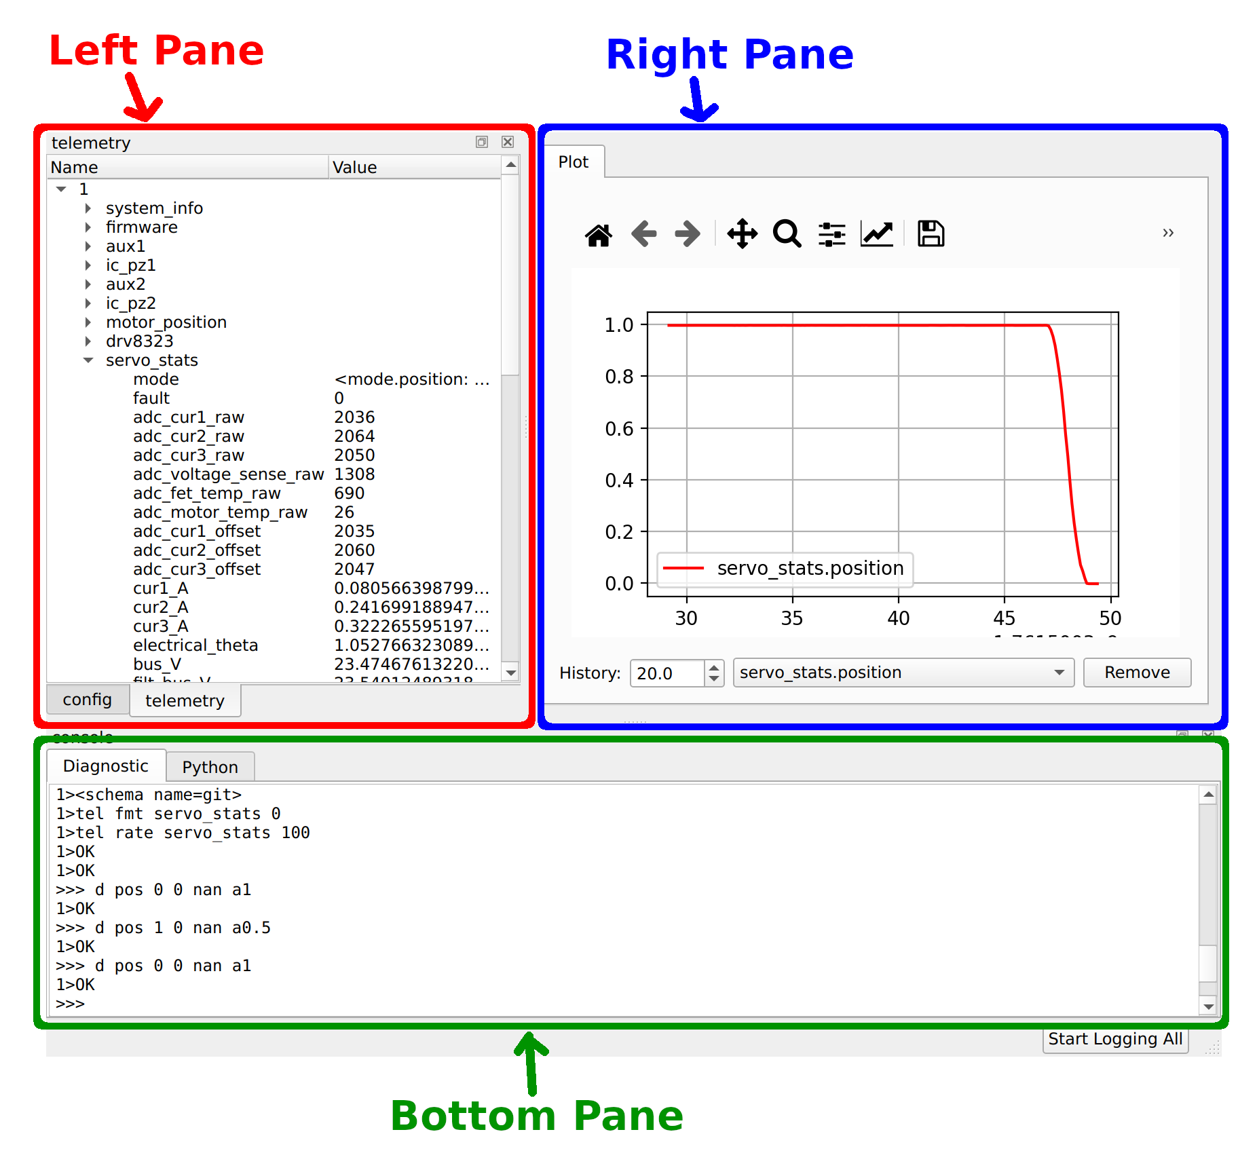
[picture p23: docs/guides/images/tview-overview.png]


### Left Pane Tabs

The left pane contains two tabs:

**Right tab (default)**: Shows a hierarchical tree of all telemetry items currently being reported by the controller.

**Left tab**: Shows a hierarchical tree of all configurable parameters. You can update parameter values by double-clicking on their value and entering a new one.

### Right Pane

The right pane displays real-time plots of telemetry items. You can populate it with plots by right-clicking on telemetry items in the telemetry tab (left pane, right tab).

### Bottom Pane

The bottom pane contains two tabs:

**Left tab - console (default)**: a command line console showing the moteus diagnostic protocol.  It:

- Shows commands sent internally by tview and their responses
- Provides an interactive console to interact with the device using the [diagnostic protocol](../protocol/diagnostic.md)

**Right tab - Python**: A python REPL that can be used to interact with the the controller(s) using the moteus python library.

## Next Steps

Now that you have the software installed and understand the tview interface, proceed to the [Configuration](configuration.md) guide to set up your moteus controller for your specific motor and application.

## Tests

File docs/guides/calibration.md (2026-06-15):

# Calibration

If you started from a bare moteus board, you will need to calibrate it for the attached motor before any control modes are possible. Calibration is required when:

- Using a new bare moteus controller for the first time
- Changing to a different motor
- Altering the mechanical registration between the controller and motor
- After certain configuration changes that affect motor characteristics

Development kits typically come pre-calibrated and do not require this step unless the motor is changed.

## Calibration Command

To calibrate your moteus controller, run the following command:

```bash
python3 -m moteus.moteus_tool --target 1 --calibrate
```

Replace `1` with the appropriate CAN-FD ID if you have configured your controller to use a different ID.

## Important Safety Warning

**WARNING: Any attached motor must be able to spin freely during calibration.**

During the calibration process:

- The motor will be spun in both directions
- The motor will reach high speeds
- Ensure no mechanical obstructions are present
- Do not apply any load to the motor shaft
- Keep hands and objects clear of the motor and any attached mechanisms

The calibration procedure measures motor electrical characteristics and encoder alignment, which requires unrestricted motor motion.

## Alternate calibration parameters

### Limited rotation

The amount of motion required for calibration can be reduced if the Kv of the motor is known in advance.  In that case, specify as an additional command line argument:

`--cal-force-kv X`

Where X is the Kv of the motor.  In this mode, moteus will only spin the rotor 360 degrees in each direction and will not perform a high speed movement.

### Very small or very large motors

During the encoder calibration process, moteus applies a constant power to the motor.  The default power, 7.5W is sufficient for many motors but not all.  If the motor is very small, it could overheat or burn if applying that much power.  If the motor is very large, 7.5W may not be enough to cause the motor to move.  This can be altered by specifying:

`--cal-motor-power X`

Where X is the power in watts to apply.  Small motors will need smaller values, large motors may need larger ones.

### Updating encoder and torque bandwidth

If your application requires changing torque or velocity very quickly there are several additional considerations.

**Torque bandwidth**: You may want to configure an alternate "bandwidth" parameter during the calibration process.  The specific value of bandwidth can be roughly used to estimate how quickly moteus can change the output torque, and how quickly it can sense velocity and position changes.  For instance, the default bandwidth is 200Hz.  This means that as a rough order of magnitude, moteus can change the torque or observe a change in velocity in 1/200 = 5ms.  Higher bandwidth values will result in the controller and motor emitting more audible noise.  Other than audible noise (which can be significant), there is not much downside to increasing the bandwidth.

`--cal-bw-hz X`

**`servo.pid_dq.max_desired_rate`**: moteus limits the rate at which the commanded phase current to the motor can change.  By default, this is set to 10000A/s.  For a moteus-r4 with a 100A current limit, that means it can take 20ms to change full range from -100A to 100A.  Many high bandwidth applications will require rates larger than this.

## Troubleshooting

If you encounter issues during calibration, such as:

- Motor not spinning
- Calibration failures or errors
- Unexpected motor behavior

Refer to the [Troubleshooting Guide](../troubleshooting/calibration.md) for common problems and solutions.

## Next Steps

After successful calibration, you can conduct the PID tuning process:

- [PID Tuning](../guides/pid-tuning.md)

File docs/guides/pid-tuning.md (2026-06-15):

# PID Tuning

When operating in position or velocity mode, moteus uses a P(I)D controller to determine what torque to apply at each instant.  The constants that control this operation need to be selected by the user.  Tuning does not have to be challenging, but does require that you understand what you are trying to accomplish.

## Theory

The purpose of the three gains:

**Proportional**: This term applies a restorative torque that is proportional to the error between the current desired position and the current measured position.  It is measured in Nm per revolution of error as measured at the output of the reducer.  It directly controls the "stiffness" of the controller.  If used in isolation, the motor will apply a fixed torque for any given error, i.e. if you manually move the motor 0.1 revolution away from the setpoint, it will apply 0.1 * the torque indefinitely, and then if you move it to be 0.2 revolution away from the setpoint, it will apply 0.2 * the torque.

**Derivative**: This term acts as a "damping" term, or viscious resistance.  As an analogy, if the proportional term is the spring in a suspension system, the derivative term is how thick the oil in the suspension is.  The torque applied from this term scales with the magnitude of the error between the desired velocity and the measured velocity.  If all other gains were zero and the motor is disturbed by hand, a larger gain makes it feel like you are working against a thicker fluid resistance.

**Integrative**:  The integrative term applies a torque that scales with the error in position integrated over time.  Many, if not most, moteus systems use no integrative term at all.  Integrative terms are hard to tune, and result in poor transient response.  However, they are the only way to achieve 0 steady state error in a loaded system.  Without an integrative term, the steady state error, while possibly very small, will never be zero.  For the integrative term there are two parameters to select, the gain itself, and the anti-windup gain term.

## Procedure

The position control P(I)D loop parameters are set in `servo.pid_position` and are selected by the user to achieve a desired control response.  Most users want a PID controller that is well damped and sufficiently stiff for their application.

Here is a possible procedure for tuning.  It is best executed using tview in a configuration where you can move the motor with your hand.  A load that is close to representative in terms of inertia, damping, and friction is best, but something is better than nothing.

1. Set kp to be small and kd, ki, and ilimit to be 0.
```
servo.pid_position.kp = 0.001
servo.pid_position.kd = 0
servo.pid_position.ki = 0
servo.pid_position.ilimit = 0
```
If you have an understanding of the system, you could select an initial kp that is larger, but you want it to be a value such that the restorative torque is very gradual and you can easily disturb the system by hand.
2. Increase kp by 50% at a time until the desired stiffness is reached.
    1. Test the current value.  A command like `d pos nan 0 nan` can be used to "hold position".  Then use your hand to move the rotor to judge the stiffness.
    2. If insufficiently stiff, increase `servo.pid_position.kp` by 50% and go back to (a)
    3. If vibration or instability results, decrease `servo.pid_position.kp` by 2x and that is roughly a good stable maximum.
3. Tune the derivative term
    1. Set kd initially to 1/100th of the kp value. For example, the following where FOO is 0.01 * the selected value for `servo.pid_position.kp`.
`servo.pid_position.kd = FOO`
    2. Test the current value.  Use `d pos nan 0 nan` to hold position.  Manually move the motor away from the setpoint, then quickly release it.  If "damped" the motor will smoothly come to a stop at the original position.  If underdamped, the motor may oscillate.
    3. If insufficiently damped, increase `servo.pid_position.kd` by 50% and go back to (a)
    4. If high frequency vibration or oscillation results, decrease `servo.pid_position.kd` by 2x and that is roughly a good stable maximum.
4. If zero steady state error is required, then an integrative term is required.  If not, leave `ilimit` at 0 and you are done.
5. Configure the integrative term.
    1. Set `servo.pid_position.ilimit` to be 20% higher than the maximum expected steady state torque.
    2. Set an initial value of `servo.pid_position.ki` equal to the `servo.pid_position.kp` term.
    3. Increase `servo.pid_position.ki` until the desired response is achieved.  `ki` will likely need to be numerically much larger than kp, on the order of 10-1000x larger.  A more representative control profile than just a "hold position" may be needed to determine if the selected integrative constants are sufficient.

## Acceleration limited trajectories

Further, it is *strongly* recommended to configure and use an acceleration limit with moteus that is physically achievable in your system.  Doing so means that the "desired" position and "desired" velocity will follow continuous, physically achievable trajectories.

- `servo.default_accel_limit` can be set in Hz / s.

If you do not set an acceleration limit, or select one that is too high to be physically achievable, your system will experience overshoot during movements and you will find it challenging to tune the P(I)D parameters to achieve a desired response.

## What not to tune

The "current loop" gains are set in `servo.pid_dq`, and are set during
calibration based on the desired torque bandwidth.  They are not
normally changed by the user.  Instead, they are selected by specifying an appropriate `--cal-bw-hz` during calibration.

## Next steps

Now you are ready to control moteus using one of the possible control modes:

- [Control](../guides/control-modes.md)

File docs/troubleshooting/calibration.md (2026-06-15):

# Troubleshooting Calibration

When setting up a [moteus controller](https://mjbots.com) with a new motor, you typically first run the automatic calibration sequence as [documented in the reference manual](../guides/calibration.md). When your system is working well, that should be all that is necessary to enable moteus to perform accurate FOC based torque control of the motor. Then you can continue on with the remainder of the items in the [Quick Start](../quick-start.md). What happens though when the automatic calibration doesn't work? This article describes the most common failure modes during calibration.

Unfortunately, most calibration failures present the same final symptom, an error like:

```
CAL timeout
```

or

```
encoder not an integral multiple of phase
```

So to resolve, you typically start with the first items in this article, then work your way down to the less common ones.

## Sense magnet issues

To operate properly using the onboard encoder, moteus requires that a diametrically magnetized sense magnet be rigidly affixed to the rotor, that it be centered laterally under the magnetic encoder on moteus, and that it has an appropriate air-gap. Let's look at each of those in turn.

First, you need a [diametrically magnetized magnet](https://www.kjmagnetics.com/magdir.asp). This is one where the axis of magnetization is sideways, so that the north pole points out of the curved side of the disc. This is contrast to axially magnetized magnets where the axis of magnetization points out of the flat side. There are a wide variety of possible options here. Every moteus controller sold at [mjbots.com](https://mjbots.com) includes an appropriate magnet, and [mjbots.com also sells spares](https://mjbots.com/products/d42dia). There are also suppliers with higher temperature magnets, like the [Radial Magnets, Inc. 9049 here at digikey](https://www.digikey.com/en/products/detail/radial-magnets-inc/9049/6030786). Sometimes however, you are converting an existing actuator to use moteus, and there is a sense magnet present already. The bad news is that it may or may not be usable with moteus and unless you know the specifications, it may be hard to know the optimal air gap required for it. In those cases it is often easiest to remove the existing magnet and replace it with a known quantity, especially if a reasonable air gap is hard to achieve.

Second, the magnet must be rigidly affixed to the rotor. No slipping is permitted whatsoever. Practically, that means that adhesive will be required at each junction between the magnet and the rotor. Common adhesives used are cyanoacrylate gel (superglue), and epoxy. For instance, if a 3D printed spacer is used, the magnet must be glued to the spacer, and the spacer must be glued to the rotor. When the rotor moves, the magnet must move. Press fits can be problematic unless the fit is designed with a well specified tolerance and relying on friction between a magnet and something it is attracted to will definitely not work.

Third, the magnet must be positioned laterally properly. This means that it needs to be centered under the magnetic encoder. For all moteus controllers but the moteus-r4, this is centered under the bolt pattern. For [moteus-r4](https://mjbots.com/products/moteus-r4-11), you should [look at the 2D CAD](https://github.com/mjbots/moteus/blob/main/hw/controller/r4.5/20210124-moteus-controller-r45-mechanical.pdf) to see where to position the magnet.

The magnet also needs an appropriate air gap between the surface of the magnet and the surface of the encoder IC. For the magnets that mjbots sells, 2mm is near the optimal air gap, with a range of 1.5mm - 2.5mm being suitable. Spacing of 0.5mm - 8mm will likely work with degraded performance.

Finally, the controller needs itself to be rigidly mounted with respect to the stator and rotor. If it is allowed to move or rotate, then the sensed angle of the rotor will not match the actual electrical angle needed for commutation, as well as degrading the quality of position control at the output.

## Electrical problems

The most common electrical problem that prevents calibration is poor or non-existent phase wire soldering. The phase wires of the motor must make a good connection to the moteus phase terminals. That means that when soldering, the joint must have reached a sufficient temperature and had sufficient flux such that the solder wicked both all around the wire, and wicked in to the phase wire terminal. Cold solder joints may show solder that does not fill the joint completely and does not form a proper fillet to the surfaces it touches or may show as visual artifacts between the wire, pad, and solder. This may result in no or an intermittent connection. A video showing what an appropriate result should look like is here:

{{ youtube("mZ9w_TaWmjQ") }}

The next most common electrical problem is a motor that is fundamentally broken. That could be one which has shorted phases, inappropriate polarity of windings, or magnets with inappropriate polarity. These problems usually only appear with second hand motors, those of low quality, or hand-built motors. The easiest way to rule it out is to test with a known working motor.

## Less Common Sense Magnet Issues

I have observed a few less common problems associated with sense magnets.

In one case, the magnet was actually glued both to the rotor and to a stationary mounting bracket, preventing the rotor from moving at all.

In other cases, magnets were allowed to exceed their rated operating temperature. The [magnets included with the moteus-r4, moteus-n1, and moteus-c1](https://mjbots.com/products/diametric-disc-magnet?variant=44912247013537) are rated to 70C.  If that is an issue, then magnets can be procured with higher rated temperatures, such as the [140C one from mjbots which is included with the moteus-x1](https://mjbots.com/products/diametric-disc-magnet?variant=44912246751393).

Sense magnets for commutation must be rigidly affixed to the rotor, \*not\* to the output of a reducer, or any linkage that may have backlash. If the magnet is attached to a reducer, then the required angular accuracy can easily exceed what the onboard encoder is capable of measuring. Linkages with backlash have the same problem.

## Mechanical Problems

If your rotor is not free to move, or has a significant load on it, then calibration can fail. Calibration will work with many kinds of reducers attached, but eventually the friction and stiction will be more than the process can manage. In some cases you can increase the power used during the lock-in phase of calibration by passing an extra option to `moteus_tool --calibrate`:

```
--cal-motor-power 5
```

The units are watts, and 5 is the default. You can increase this, but at higher values, you may run the risk of overheating your motor during the encoder calibration process.

If a suitable power cannot be found, then it may be required to design the motor and controller as a sub-assembly which can be first calibrated and then attached to the reducer.

## The bad news

The bad news is that the error checking in the calibration process is not foolproof. i.e. it is possible for a setup that is broken to still report that calibration completed successfully. The two biggest indicators that it did not actually work are that the Kv value reported during calibration is grossly incorrect or that position or torque control do not work reliably. If either of those happen, you need to work through the above potential causes and rule them out one by one.

## The good news

The good news is that if you have a working motor, an appropriate magnet, the magnet is rigidly affixed to the rotor and positioned properly, and your phase wire soldering followed proper technique, calibration should succeed virtually 100% of the time.

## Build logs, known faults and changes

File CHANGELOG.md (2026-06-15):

# Changelog

This file tracks notable changes per shipped component. Each component is
released independently; see [RELEASING.md](RELEASING.md) for the process.

The format is loosely based on [Keep a Changelog](https://keepachangelog.com/).

## firmware

### Unreleased

(no entries yet)

### 1.0.0 - 2026-05-28

#### Firmware improvements

- Use a CSA gain based kCurrentSampleTime - this reduces the effective modulation depth in all configurations, more with the default CSA gain, but is actually correct and does not result in spurious current sense noise at high duty cycles no matter what CSA gain is configured
- Actually count errors if hall sensors flip more than one bit at a time
- Fix the used bitrate for I2C2, which affects I2C on aux2.  Previously, actual operation was at half the configured bitrate.
- When targetting a near-zero speed with an acceleration limit, in some cases we could oscillate.  Fix this to reach the target without oscillation.
- Force a hall sensor update on boot, if we otherwise got unlucky, a hall configuration could report no encoder configured
- For hall sensors, if our "slow velocity" heuristic coasts to the end of a sector, but then no more hall updates arrive, gradually recenter back to the center of the sector

#### Other firmware behavior changes

- Fix various undefined behaviors and assertions in the firmware that could be triggered by misconfiguration.

#### Utilities and examples

- `utils/measure_ma732_bct.py` is more likely to work if Y axis trimming is required.
- `utils/measure_inertia.py` has improved accuracy
- Various compensation scripts could fail if encoder values were unfortunately situated relative to the pi/-pi boundary
- `utils/plot_highrate.py` accepts hex / oct / bin literals for --emit-debug
- `lib/python/examples/ruckig_multiservo.py` both works properly on Windows and reports the mode and fault for each device

#### Release engineering

- First semver release, ABI bumped to 0x010000 (1.0.0), although no functional ABI changes were made.
- Implement a ubsan build, verify it in CI.
- Support building on Ubuntu 26.04

## python

### Unreleased

(no entries yet)

### 1.0.0 - 2026-05-28

#### Improvements

- `moteus_tool --calibrate` for controllers configured for hall commutation now calibrate a fine position for each hall transition, which improves performance and consistency for hall based configurations

#### Fixes

- `moteus.move_to` now respects the `velocity_limit` argument across all devices
- `moteus.move_to` works properly when exiting the stopped state
- Don't inject `await` when it isn't needed, rending some python mode definitions possible that previously would have triggered syntax errors
- Fix the order of D and Q axes for current mode requests

## cpp

### Unreleased

(no entries yet)

#### 1.0.0 - 2026-05-28

* First semver based release.

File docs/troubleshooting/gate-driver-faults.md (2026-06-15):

# Troubleshooting Gate Driver Faults

Certain types of electrical problems in moteus can result in the onboard MOSFET gate drivers declaring an error condition.  When that happens, moteus will report fault 33.  This document describes how to troubleshoot the issue.

## Identifying the cause

To determine *which* fault the gate driver flagged, you need to look at the `drv8323` tree in tview or with `python -m moteus.moteus_tool -t 1 --read drv8323`.  Each fault has a different boolean value associated with it, and multiple can be flagged at the same time.  From a diagnostic perspective though, they boil down into two categories:

## Recoverable faults

The only fault type that, if repeatable, is easily recoverable is the `uvlo=true` fault.  This means that the gate driver identified the input supply voltage dropped below the minimum operation threshold.  It happens when moteus attempts to draw more power than the supply or battery can provide.  Depending upon the cause, there are several potential resolutions:

**moteus needs to output more torque/power**: If the fault triggered but moteus was not yet applying sufficient torque for your application, then you must change your supply to be able to provide more power.  If the supply is a current limited lab supply, you could increase the current limit.  If it is a fixed current wall supply, you could switch to one with a higher power output.  If it is a battery, you could switch to one with a higher peak current rating.  It is also possible to occur due to poor supply wiring, i.e. if the resistance of the supply power cables is too high.

**moteus should not attempt to draw that much power**: If moteus was attempting to apply more torque or power than is desirable, there are two limits which can be adjusted.

1. `servo.max_current_A` - This will determine the maximum phase current moteus can output and will correspond to the maximum amount of torque it can output.  This does not directly correlate with supply power, as the supply power required also scales linearly with the motor velocity.  However, it is good to ensure this is not set larger than it needs to be.
2. `servo.max_power_W` - This will determine the maximum amount of power moteus can output to the motor, and thus roughly the amount of supply power it can consume.  If using a power supply with known voltage and current capability, you can set this to be some fraction of that power to leave sufficient margin.

## Unrecoverable faults

Most non-uvlo faults the gate driver reports indicate that the controller has suffered electrical damage.  Most of the reasons are laid out in the electrical section of the user guide:

- [Using moteus: Electrical](../guides/electrical-setup.md)

i.e. poor wire construction can result in micro-arcing which further causes large voltage transients either at the supply terminals, or the motor phase terminals.  Lack of inrush current management also results in large voltage transients at the supply terminals.  Poor strain relief of XT30 connectors, once again, can cause micro-arcing and large voltage transients.

In these cases, it may be possible to recover the controller by replacing components, but doing so requires moderate to advanced SMT rework capabilities that are beyond most users.  Usually the appropriate action is to identify which of the electrical installation guidelines were not adhered to, address them, then replace the controller with a new one.

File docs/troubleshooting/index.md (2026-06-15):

# Troubleshooting

Common issues and solutions for moteus controllers.

- [Calibration Issues](calibration.md) - Problems during motor calibration
- [No Motion](no-motion.md) - Motor not responding to commands
- [Limited Torque](limited-torque.md) - Motor not reaching expected torque
- [Gate Driver Faults](gate-driver-faults.md) - DRV8323 fault codes
- [Timeout Mode 11](timeout-mode-11.md) - Communication timeout errors
- [Overvoltage Fault 34](overvoltage-fault-34.md) - Regenerative braking issues

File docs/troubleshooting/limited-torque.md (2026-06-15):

# Troubleshooting Limited Torque

If moteus is able to control a motor, but is unable produce sufficient torque for your application's needs, this post describes diagnostic steps.

## Outline

There are a few main classes of things that can limit torque.

1. **Misconfiguration**:  Things that fall into this category include PID constants that are not tuned or an overly aggressive current limit or thermal limit.
2. **Under-cooled controller or motor**: If the controller and motor are properly sized for the application, they may still require thermal management to achieve those goals.
3. **Under-sized controller or motor**: If thermal management alone is insufficient, or is not practical, then either a larger controller or larger motor may be required.
4. **Insufficient supply voltage**: With low-Kv motors, it is possible for supply voltage to be a limiting factor.

## Diagnosing

First you need to understand which of the above three classes you are in.  To do so, there are some possible diagnostics and other things to check.

### Output Limit Reasons

As of firmware version 2025-07-21, the firmware will report if a factor is limiting the output current via the "fault" register while in position mode.  The set of possible values are:

- **96 max_velocity**: Maximum velocity: If the observed velocity exceeds the configured maximum velocity, torque is limited in the direction that would cause the velocity to increase.  This is configured with `servo.max_velocity`.
- **97 max_power**: Maximum power: The total power of the output is limited through a combination of a board power profile and `servo.max_power_W`.  [See this post for more](https://blog.mjbots.com/2025/03/29/moaar-power/).
- **98 BEMF**: Maximum system voltage: The supply voltage, combined with the back EMF of the motor and the phase resistance does not permit more current to be applied.
- **99 max_current**: Maximum current: There is a system wide maximum output phase current that is configured in `servo.max_current_A`.
- **100 fault_temperature**:  Temperature: The onboard FET temperature sensor can limit the output current.  This threshold is set in the current firmware with `servo.fault_temperature`/`servo.temperature_margin`.
- **101 motor_temperature**: Temperature: The motor temperature sensor can also limit the output current.  This is configured in `servo.motor_fault_temperature`/`servo.motor_temperature_margin`.
- **102 max_torque**: Maximum torque: With each position mode command, the client can specify a maximum torque to use.  If the combination of the onboard PID and commanded feedforward torque exceeds this, then limiting occurs.
- **103 position_bounds**: Position bounds: If the current position is outside of `servopos.position_min` and `servopos.position_max`, then torque is limited in the direction that would push the motor further outside the bounds.
- **104 flux_braking**: Flux braking: The input voltage is too high and the controller is dissipating energy in the motor windings.

### Other possibilities

If none of the above limiting flags are present, then the remaining options include:

#### Not stiff enough PID tuning

The torque applied by moteus (aside from any feedforward torque), is determined by the error between the desired and measured position and the error between the desired and measured velocity.  If the constants controlling this process are too low, then moteus will apply very little torque even for large errors.

One common way this occurs with moteus is:

1. A PID tuning is created
2. Later, a reducer is configured using `motor_position.rotor_to_output_ratio`
3. Wow, now moteus doesn't output much torque

The important point to note here is that the PID terms for the moteus control loop are measured at the *output* of any reducer.  Thus if kp=1, that means apply 1Nm of torque *at the output* for 1 revolution of error *at the output*.  With a reducer, that means the effective gains at the rotor are reduced by the reduction squared.

So, after configuring a reducer, you can either re-tune the PID gains, or increase the gains by the square of the reduction.

Sample:

```
servo.pid_position.kp = 4
servo.pid_position.kd = 0.05
motor_position.rotor_to_output_ratio = 1
```

You test this and it works great.  Then you configure the 8x reducer which was always present.

```
motor_position.rotor_to_output_ratio = 0.125
```

And now all of a sudden the controller barely does anything at all.
To have equivalent stiffness, you now need to increase the kp and kd
gains by a factor of `8 ** 2 = 64`.

```
servo.pid_position.kp = 256
servo.pid_position.kd = 3.2
```

#### Invalidated calibration

If your calibration was invalidated, it can result in lack of torque.  Invalidation can happen for any of the reasons in the [calibration troubleshooting guide](calibration.md), and include:

- A sense magnet that was not rigidly affixed to the rotor, say because adhesive not used at a joint
- A sense magnet that exceeded its rated temperature
- The controller mounting shifted

To test these hypotheses, re-calibrate the motor and check again.  If
the problem is resolved, then you need to identify which of the above
issues was the most likely culprit and resolve it.

#### Other "limiting like things"

There are some "limiting-like" features that do not report through the
fault code mechanism.  If position bounds are configured, the control
position is limited to stay within those bounds.  This does not
directly limit torque, so is not reported via this mechanism.

Similarly, if the commanded velocity exceeds either the velocity
limit, `velocity.max_velocity`, or `servo_stats.motor_max_velocity`,
then it is truncated to stay within.  These limits are not reported
via the fault code mechanism.

## Resolution

If the error was mis-configuration, fix it and you are done.

If the error was not mis-configuration, then the resolution depends upon what was causing the limiting.

### Thermal limiting

If the limit was thermal, then your options are:

1. apply cooling to whatever was hot
2. use a bigger controller or motor for whatever was hot
3. use a reducer, or if already using a reducer, use a bigger one

### Maximum current

If you hit the controller maximum current limit, then your options are:

1. use a different motor
2. use a controller with a higher current limit
3. use a reducer, or if already using a reducer, use a bigger one

### BEMF or `servo_stats.motor_max_velocity`

If you are limited by the back EMF of your motor, then your options are:

1. use a higher supply voltage
2. use a different motor with a higher Kv rating

### max power

Here, your options are:

1. configure a higher PWM frequency
2. use a bigger controller
3. use a different motor
4. use a reducer, or if already using a reducer, use a bigger one

## Resolution caveats

### Reducers

If considering using a reducer or a bigger reducer, the biggest caveat is that the maximum speed will be decreased by a corresponding amount.

Secondarily, most reducers have backlash and will add static and dynamic friction to your system and may have limits on maximum torque or speed that become limiters.

### PWM frequency

If increasing the PWM frequency to improve peak power, this will also decrease the efficiency of moteus.  That will result in lower continuous output current and power ratings.

### Cooling

The obvious downsides of cooling are noise, lower reliability, and increased power consumption even when under no load.

## moteus performance analysis tool

If attempting to design a motor system to achieve a particular goal, it may be useful to use the moteus performance analysis too, which lets you vary these parameters and measure the resulting performance of the system.

- [https://mjbots.github.io/moteus/mpat.html](https://mjbots.github.io/moteus/mpat.html)
- [mpat blog post](https://blog.mjbots.com/2025/07/17/moteus-performance-analysis-tool-v2/)

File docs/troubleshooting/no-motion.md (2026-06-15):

# Troubleshooting No Motion

You sent a command to moteus, or ran a script, but nothing moved.  This article will describe what steps you can take to diagnose and resolve the issue.

## Using tview

If you sent a `d pos` command from tview, there are a few possibilities.

**Invalid Syntax**: If the diagnostic channel responds with an OK, then this is not the problem.  If it responds otherwise, then the error message will give you a clue as to the problem.  The syntax for the `d pos` command can be found in the [diagnostic protocol reference manual]( http://localhost:8000/mjbots/moteus/protocol/diagnostic/#d-pos).

**Position Mode Fault**: If the diagnostic channel responded OK, then to identify the problem you must look at the current reported mode and fault status.  They will be present as the first two items in the `servo_stats` telemetry channel.  Common problems when first attempting control are:

 - "39 (outside bounds)": `servopos.position_min` and `servopos.position_max` are either not configured, or the motor starting position is outside the configured bounds.  Setting either to `nan` will disable it.
 - "33 (gate driver fault)": this indicates that the onboard MOSFET gate driver reported a fault.  To know which one, you will need to expand the `drv8323` telemetry channel.  The only "easy" problem to solve is `uvlo` which indicates that moteus attempted to draw more power than your supply could provide.
 - "43 (no position)": the most common reason for this fault is that the controller has not been calibrated yet.  See the [quick start section on calibration](../guides/calibration.md).

Once the cause of the fault has been identified, it can be cleared by sending:

`d stop`

Then the command in question can be attempted again.

## From a script or application

If you have a python script, C++ application, or other tool which is commanding moteus and it does not move, there are a few tools you can use.

**Request and display the mode and fault**: If your application does not already request and display the mode and fault it should do so.

**Log CAN-FD data**: If the application cannot be modified or it is difficult to do so, you can either (a) if it is using the python library use the `--can-debug OUT.LOG` command flag to save a record of all frames sent and received or (b) attach a second CAN-FD adapter to the bus and use it to log data.

Once you have data, it can be examined using `utils/decode_can_frame.py` to see what moteus is reporting.

Problems may be the same as from the "Using tview" section above.

Another common problem with applications using the register protocol (what the python and C++ library does), is watchdog timeouts.  For the register protocol, by default, moteus requires commands arrive at least every 100ms or it will enter mode 11, the timeout mode.  Once in this mode, a "stop" command must be sent to clear it.

The watchdog timer configuration is described in [the reference manual](../reference/configuration.md#servodefault_timeout_s).

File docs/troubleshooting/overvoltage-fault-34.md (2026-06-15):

# Troubleshooting Overvoltage Fault 34

moteus brushless motor controllers both apply power to motors and, depending upon the mode and external system state, can act as a generator, often termed regenerative braking.  When acting as a generator energy is emitted to the input DC bus -- this causes the voltage to rise at a rate depending upon the characteristics of the supply.  If the voltage rises far enough and for a sufficient time to trigger it, [flux braking](../guides/electrical-setup.md#flux-braking) may cause some energy to be expended in the windings of the motor.  If the regenerative braking energy increases rapidly, or is larger than the configured flux braking can dissipate, the voltage can rise above the configured fault voltage in `servo.max_voltage`, which will trigger a fault.

If you are seeing fault 34 in your application, there are several largely independent methods that can be attempted to resolve the problem.

## Configuring acceleration limits

For flux braking to operate, the rate at which regenerative power increases must be limited.  The easiest way to do so is to use acceleration limits that are as low as your application can tolerate.  The default acceleration limit can be set with the configurable parameter:

```
servo.default_accel_limit
```

Or the limit can be sent with individual position mode commands.

If you don't know what acceleration is appropriate, you can either:

- use back of the envelope calculations of the form, "I know the system needs to change from velocity X Hz to velocity Y Hz in Z s, thus the acceleration is (Y - X) / Z"
- select a large acceleration limit that is unlikely to cause problems, say 10000Hz/s.  Then lower it progressively until your application has issues.  Select a final value a healthy margin above where the issues started.

## Limit regenerated power with `servo.max_regen_power_W`

When generating power, by default moteus sends all of this energy back to the DC bus.  This can cause the voltage to rise if the supply has non-trivial impedance.  By setting `servo.max_regen_power_W`, you can limit how much regenerated power is allowed to flow back to the bus.  Any excess is pre-emptively dissipated in the motor windings by injecting d-axis current.

For example, to allow no more than 50 watts of regeneration:

```
conf set servo.max_regen_power_W 50
```

Setting this to `0` will cause all regenerated energy to be dissipated in the motor windings, preventing any regenerative current from reaching the bus up to the limit of the maximum configured current and system voltage. Setting it to `nan` (the default) disables the feature entirely.

This is most effective when used in conjunction with an acceleration limit.  The acceleration limit controls the rate at which braking torque is applied, and `max_regen_power_W` dissipates excess energy that makes it past the acceleration limit.

### Choosing a value

- If your supply cannot absorb any regenerative energy (e.g. a mains powered supply with no bus capacitance), set this to a small number like `10` or `0`.
- If your supply can absorb some current (e.g. a battery), set this to approximately `V_bus * I_charge_max`.  For example, a 24V battery that can accept 2A of charge current: `servo.max_regen_power_W 48`.
- If you are unsure, start with a value of `0` and increase it until you see fault 34 again, then back off by roughly 50%.

### Thermal considerations

The d-axis current injected by this feature dissipates power as heat in the motor windings.  At the maximum current (set by `servo.max_current_A`) with resistance R, the maximum sustained dissipation is `1.5 * I² * R`.  For a motor with R=0.05Ω and max current 40A, this is 120W.  Ensure the motor can tolerate the additional heating, particularly during sustained or repeated deceleration events.

## Lower the impedance of your input supply to regenerative power

By lowering the impedance of your input supply, you decrease the rate at which the voltage rises for a given amount of regenerative energy.  There are several approaches to this.

### Increase battery current rating

If you are using batteries that are capable of charging as your power supply, you can select batteries that have a higher charging current rating.

### Add bus capacitance

If you have a mains powered supply which is incapable of accepting regenerative energy, or it is not desirable to change the battery, you can add additional capacitance to the DC input bus.  There are several considerations when doing so:

- **Inrush current management**: Per [the electrical setup guide](../guides/electrical-setup.md#inrush-current-management), whatever inrush current management solution you are using must tolerate the additional capacitance.  If you are using a mjbots power_dist or mjpower-ss, the total system capacitance must be no more than 4000uF.  mains powered supplies may be able to handle much larger bus capacitances, although their reference documentation should be checked to validate that.  In general, the larger the capacitance the better for resolving over-voltage faults, presuming you stay within the limits of your inrush current solution.

- **Capacitor rating**: The selected capacitors should have a voltage rating sufficient for the maximum voltage the bus will expect with a design margin appropriate to your application.  Additionally, the ESR (equivalent series resistance), should be low enough to control the magnitude of the voltage rise.

### Switch to a battery

If you are using a mains powered supply, it may be possible to switch to a battery solution where the battery can be charged.  When doing so, it is important to ensure that inrush current is managed appropriately.

## Configuration changes

If the above solutions were unable to resolve the problem, or the system performance is still not at the desired level, there are a few other parameters which can help some, although not to the same degree.

### `servo.flux_brake_margin_voltage`

Flux braking works by monitoring a filtered version of the system voltage and dissipating more energy in the windings as this increases.  By increasing the range of voltages where this process occurs, the system will have more time to respond as the voltage rises.  The threshold points that are relevant are:

- `servo.max_voltage - servo.flux_brake_margin_voltage`: This voltage is the point where flux braking begins.
- `servo.max_voltage`: When the voltage reaches this point, the over-voltage fault will trigger.

You can increase `servo.flux_brake_margin_voltage` until the trigger point is maybe 1V above your nominal system voltage or fully charged voltage if on a battery.  You can also increase `servo.max_voltage` and `servo.flux_brake_margin_voltage` at the same time to give even more room.

### `servo.flux_brake_resistance`

This constant determines how much energy is dissipated in the windigs for a given amount of voltage rise.  Lower values are more aggressive and will dissipate more energy, but can be less stable.  Unless you have a good mechanism for verifying stability, it is not recommended to lower this more than a factor of 2x from the default.

### `servo.pid_dq.max_desired_rate`

This configuration value selects the maximum rate at which desired current can change.  By default, it is relatively slow at 10000A/s.  However, if you have raised it previously, lowering it back down can help reduce the rate at which regenerative power is increased.  If your application can tolerate it, lowering further will increase the effectiveness of flux braking.

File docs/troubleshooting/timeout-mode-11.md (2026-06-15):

# moteus reports mode 11 - Timeout

After performing some initial validation using tview, maybe you port your motion profile to a python or C++ application to get ready for a deployment.  However, often users at this point will start seeing moteus enter mode 11, the timeout mode, after which it stops accepting commands and acts to damp motion.  This guide tells you why that happens and how to fix it.

## Rationale

moteus implements a "watchdog timer" for commands that arrive over CAN-FD.  Once any command is received, the next one must be received within a certain time period.  If it doesn't, then moteus will enter the timeout mode.

There are a few reasons for this feature:

1. **Safety**: In an actual deployment, moteus could have been commanded to make a large or fast movement indefinitely.  If your application crashes, or the computer hosting it is powered down, you probably don't want moteus continuing.
2. **Convenience**: When testing an application, if you exit the application you typically want moteus to stop doing whatever it was doing as well.

Once in the timeout mode, moteus will only leave it upon receiving a stop command.  This prevents moteus from resuming unexpectedly.

When using diagnostic mode commands like when typing into the diagnostic channel console in tview, moteus defaults to an infinite watchdog duration for the sake of convenience.  This is why the problem most often appears after switching to a script.  Both the python and C++ library default to using the more efficient register mode commands.

## Fixes

If you get the timeout here are ways to resolve it:

### Disable or extend the timeout duration

The length of time moteus waits is configurable at:

```
servo.default_timeout_s
```

[(listed here in the reference)](../reference/configuration.md#servodefault_timeout_s)

To disable it, use `nan`, otherwise specify a floating point number of seconds.

### Structure your application to send commands at a regular interval

To maintain the benefits of the watchdog, your application needs to continually send commands to moteus.  That means even when the application is waiting, it still needs to be sending commands.  Fortunately, for many moteus commands, if the target velocity was 0, you can keep sending the same command over and over again.

=== "Python"

    ```python
    # Don't do this:
    #  await asyncio.sleep(5)

    # Instead, do this:
    start = time.time()
    while time.time() - start < 5:
      await c.set_position(velocity=0.0, query=True)
      await asyncio.sleep(0.02)
    ```

=== "C++"

    ```cpp
    // Don't do this.
    //  ::usleep(1000000);

    // Instead, do this:
    #include <chrono>

    double get_time() {
      using namespace std::chrono;
      return duration<double>(system_clock::now().time_since_epoch()).count();
    }

    int main() {
      // setup ...

      const auto start = get_time();
      while (get_time() - start < 5) {
        mjbots::moteus::PositionMode::Command cmd;
        cmd.velocity = 0.0;
        cmd.position = NaN;
        c.SetPosition(cmd);

        ::usleep(10000);
      }

      return 0;
    }
    ```

### A combination of the above two

It may be that even after restructuring your application to send commands more regularly, it makes sense to increase, but not disable the default watchdog timeout.

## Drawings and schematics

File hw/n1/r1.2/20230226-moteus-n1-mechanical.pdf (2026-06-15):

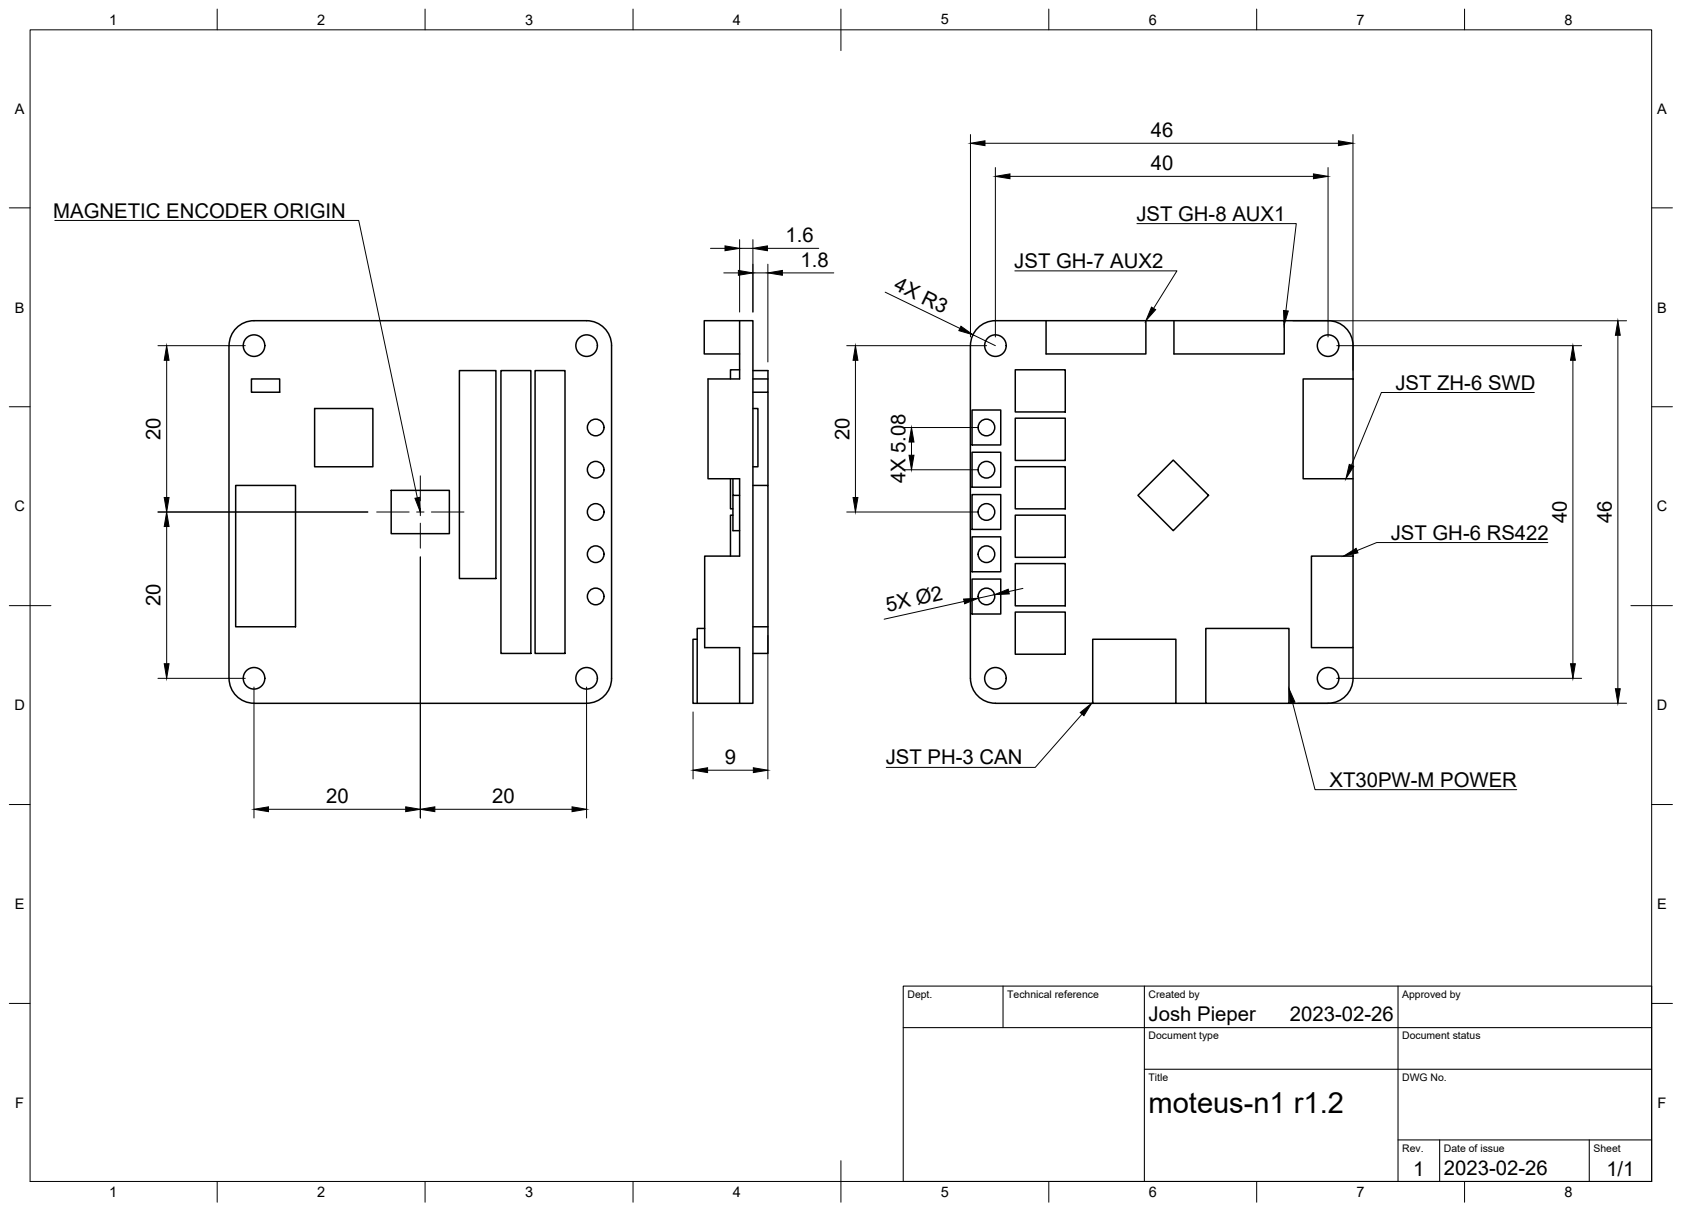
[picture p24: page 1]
Title; DWG No.; Rev.; Date of issue; Sheet; moteus-n1 r1.2; XT30PW-M POWER; JST GH-7 AUX2; JST GH-8 AUX1; JST GH-6 RS422 4X 5.08 20

MAGNETIC ENCODER ORIGIN

JST ZH-6 SWD

JST PH-3 CAN

Dept. | Technical reference | Created by Josh Pieper 2023-02-26 | Approved by

Document type | Document status

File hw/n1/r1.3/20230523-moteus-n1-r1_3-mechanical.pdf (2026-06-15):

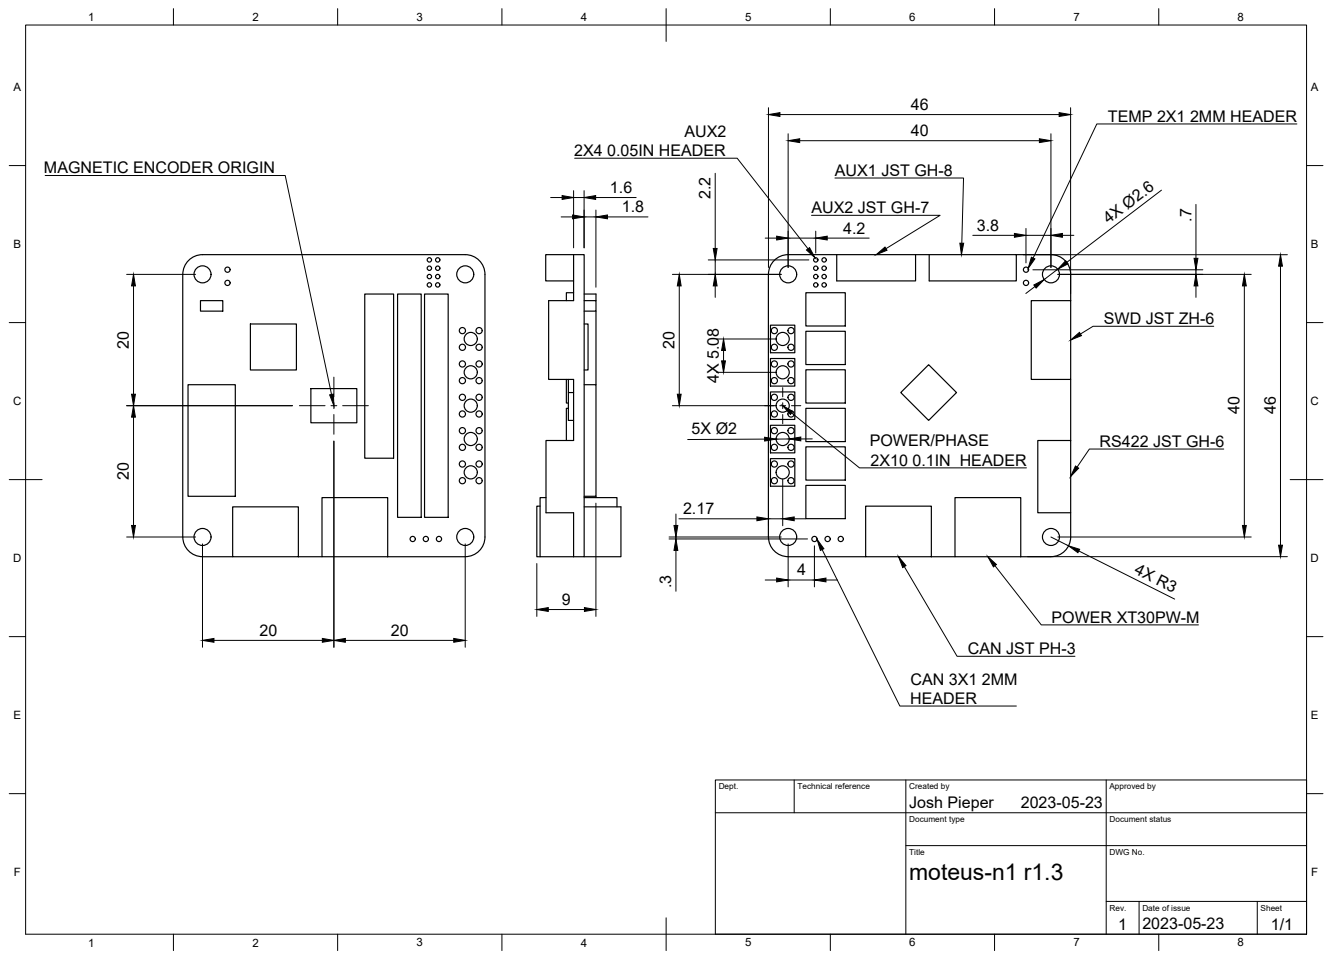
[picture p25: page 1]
Title; DWG No.; Rev.; Date of issue; Sheet; moteus-n1 r1.3; POWER XT30PW-M; AUX2 JST GH-7; AUX1 JST GH-8; RS422 JST GH-6 4X 5.08 20; POWER/PHASE; 2X10 0.1IN HEADER; 2X4 0.05IN HEADER .3; CAN 3X1 2MM; TEMP 2X1 2MM HEADER

MAGNETIC ENCODER ORIGIN

SWD JST ZH-6

CAN JST PH-3

Dept. | Technical reference | Created by Josh Pieper 2023-05-23 | Approved by

Document type | Document status

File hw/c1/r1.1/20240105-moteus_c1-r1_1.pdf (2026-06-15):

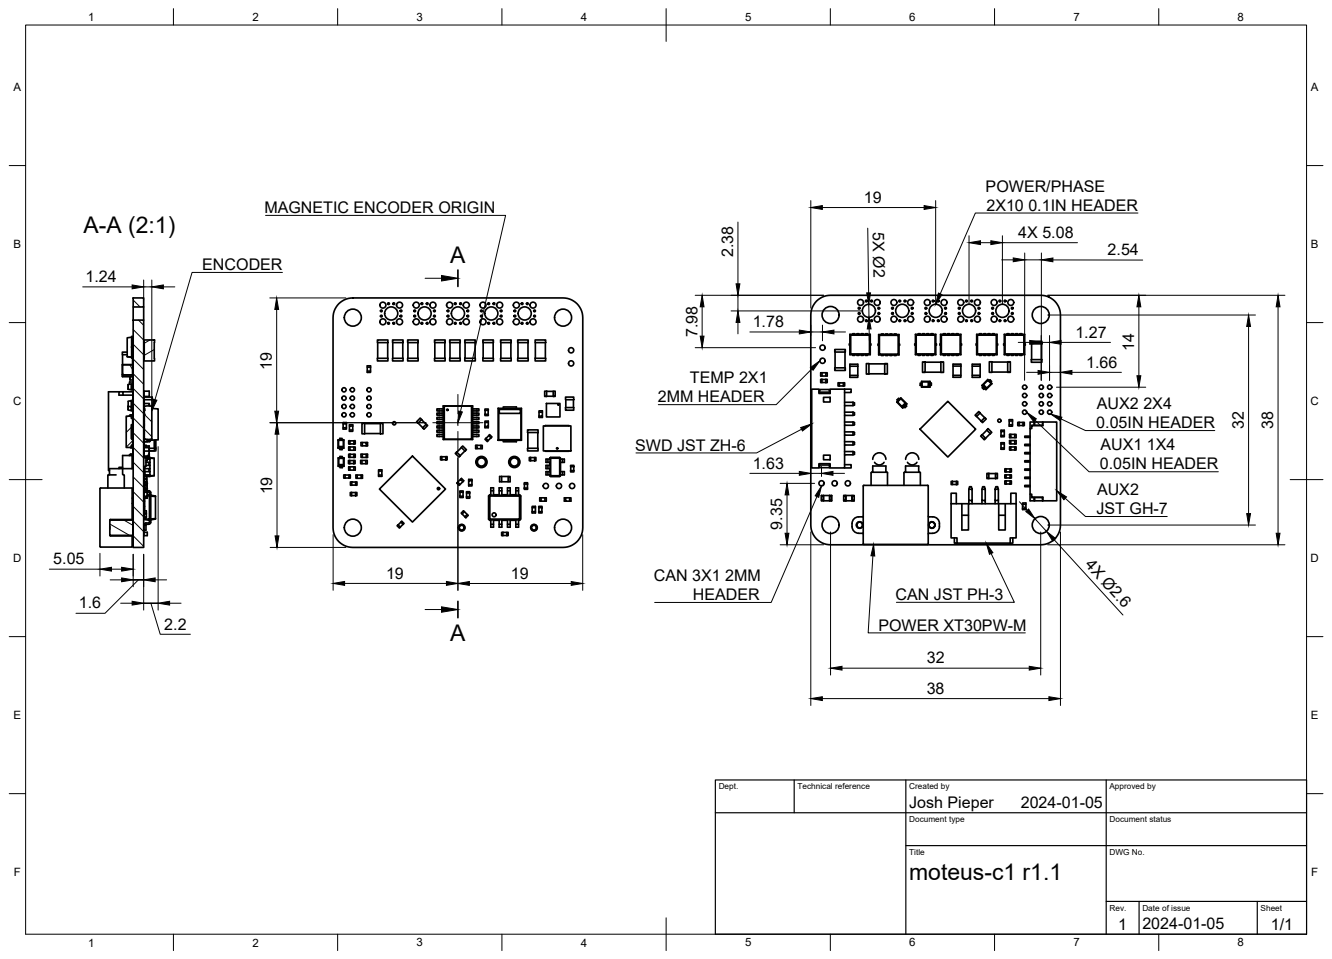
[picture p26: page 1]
Title; DWG No.; Rev.; Date of issue; Sheet; moteus-c1 r1.1; Josh Pieper; POWER XT30PW-M; 2X10 0.1IN HEADER; TEMP 2X1 2MM HEADER; CAN 3X1 2MM; JST GH-7; AUX2 2X4 0.05IN HEADER AUX1 1X4 0.05IN HEADER

MAGNETIC ENCODER ORIGIN

SWD JST ZH-6

CAN JST PH-3

Dept. | Technical reference | Created by 2024-01-05 | Approved by

Document type | Document status

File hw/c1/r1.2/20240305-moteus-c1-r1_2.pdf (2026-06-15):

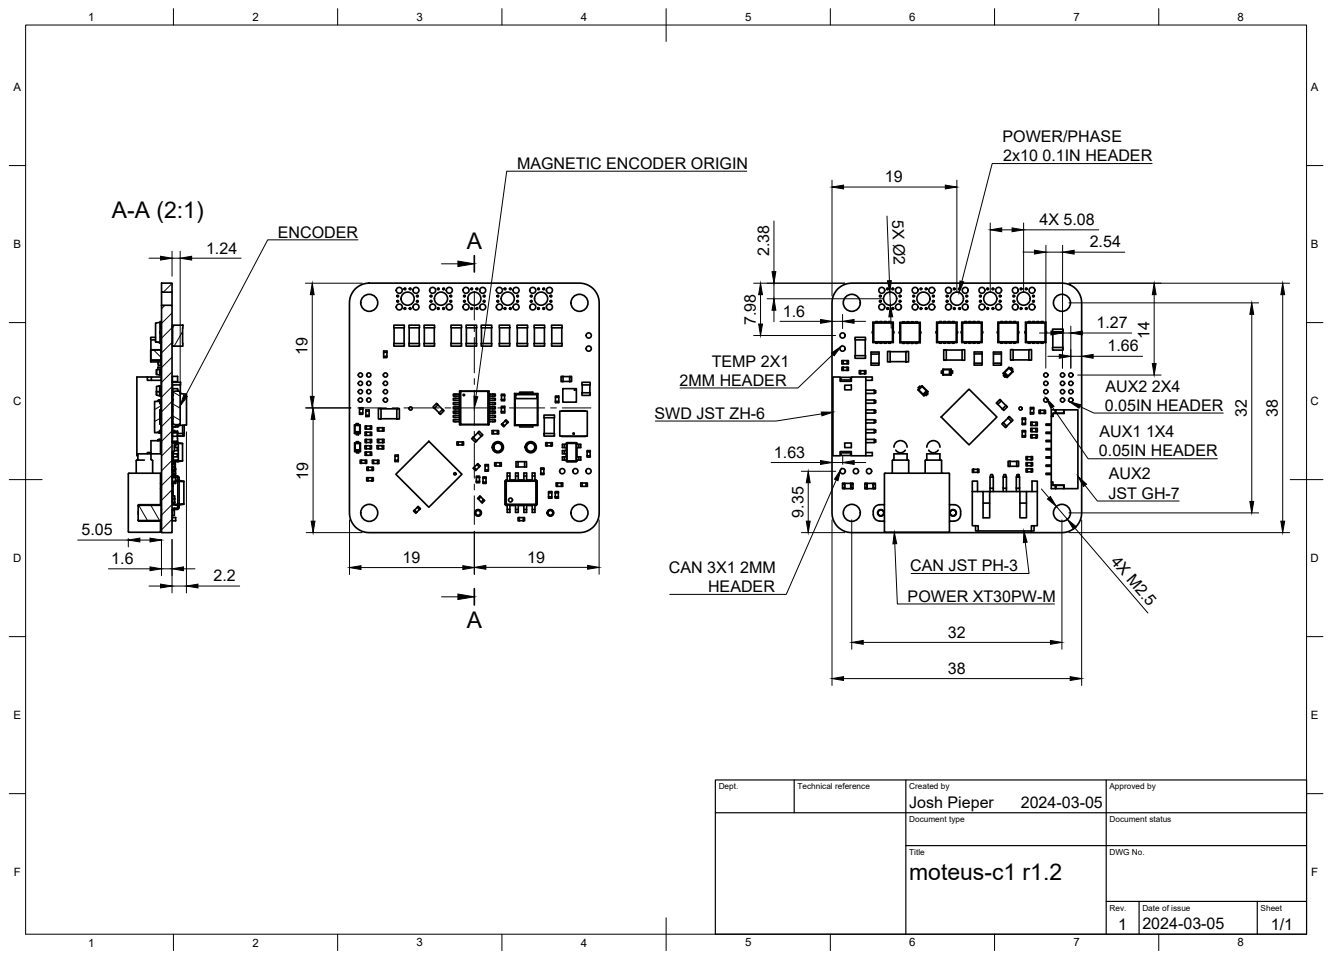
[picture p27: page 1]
Title; DWG No.; Rev.; Date of issue; Sheet; moteus-c1 r1.2; TEMP 2X1 2MM HEADER; CAN 3X1 2MM; HEADER; POWER XT30PW-M; JST GH-7; AUX1 1X4 0.05IN HEADER; AUX2 2X4 0.05IN HEADER

2x10 0.1IN HEADER MAGNETIC ENCODER ORIGIN 19 19

SWD JST ZH-6

CAN JST PH-3

Dept. | Technical reference | Created by Josh Pieper 2024-03-05 | Approved by

Document type | Document status

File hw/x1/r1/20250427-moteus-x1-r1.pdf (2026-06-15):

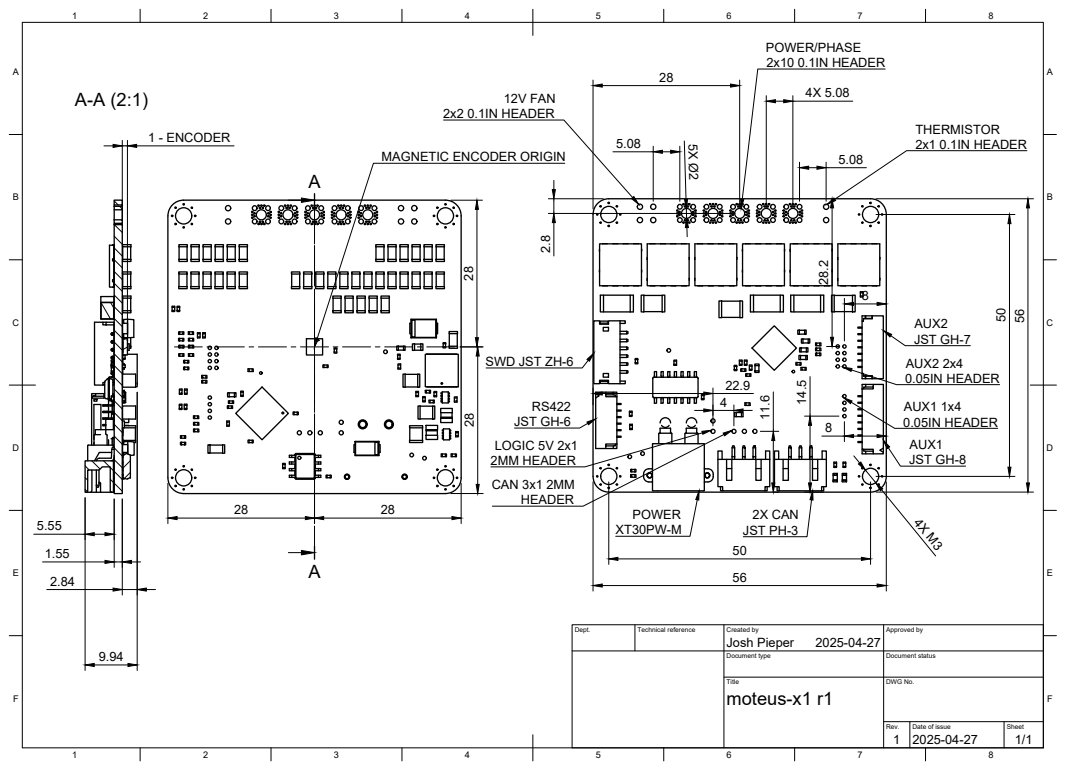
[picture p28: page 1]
Title; DWG No.; Rev.; Date of issue; Sheet; moteus-x1 r1; Josh Pieper; 2x10 0.1IN HEADER; JST GH-7; JST GH-8; AUX2 2x4 0.05IN HEADER; AUX1 1x4 0.05IN HEADER; JST GH-6; 2X CAN JST PH-3; CAN 3x1 2MM; LOGIC 5V 2x1 2MM HEADER; 1 - ENCODER; 12V FAN 2x2 0.1IN HEADER; 2x1 0.1IN HEADER

MAGNETIC ENCODER ORIGIN

SWD JST ZH-6

Dept. | Technical reference | Created by 2025-04-27 | Approved by

Document type | Document status

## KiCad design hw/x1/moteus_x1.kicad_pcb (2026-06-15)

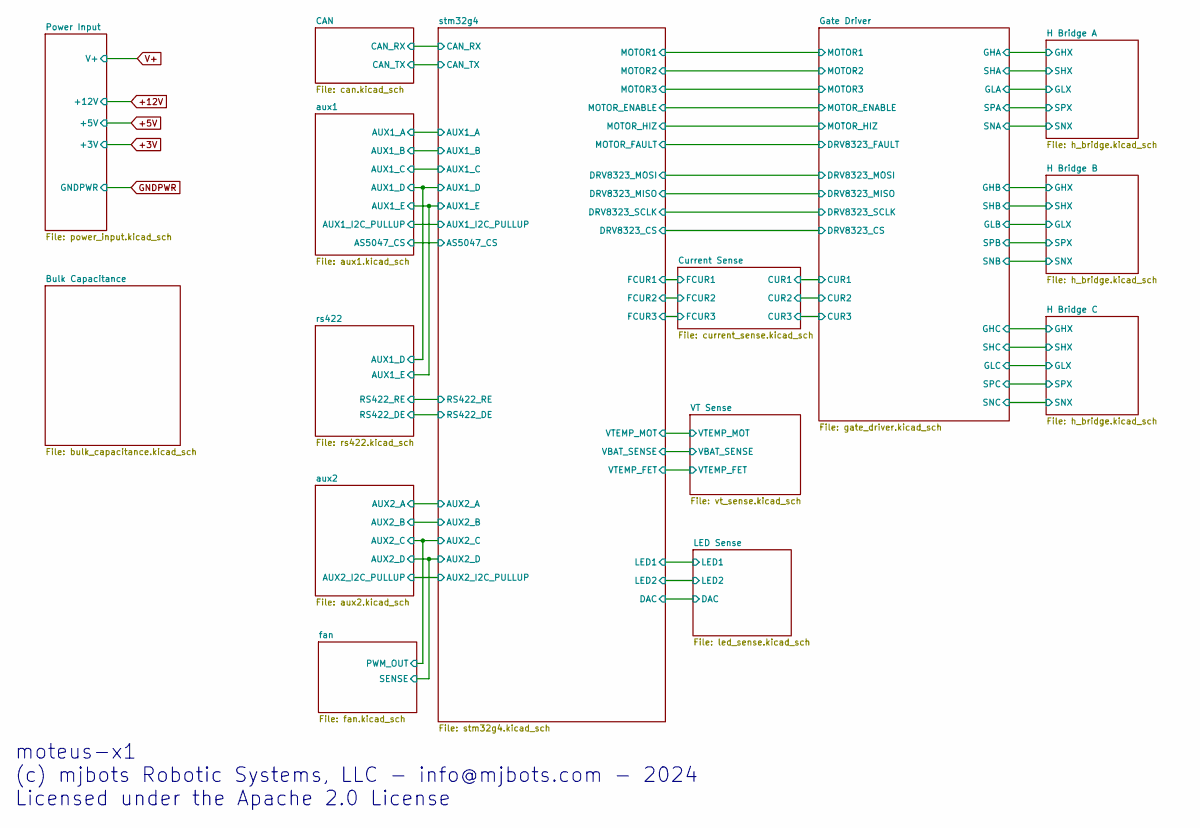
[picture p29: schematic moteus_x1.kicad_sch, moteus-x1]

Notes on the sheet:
moteus-x1 (c) mjbots Robotic Systems, LLC - info@mjbots.com - 2024 Licensed under the Apache 2.0 License

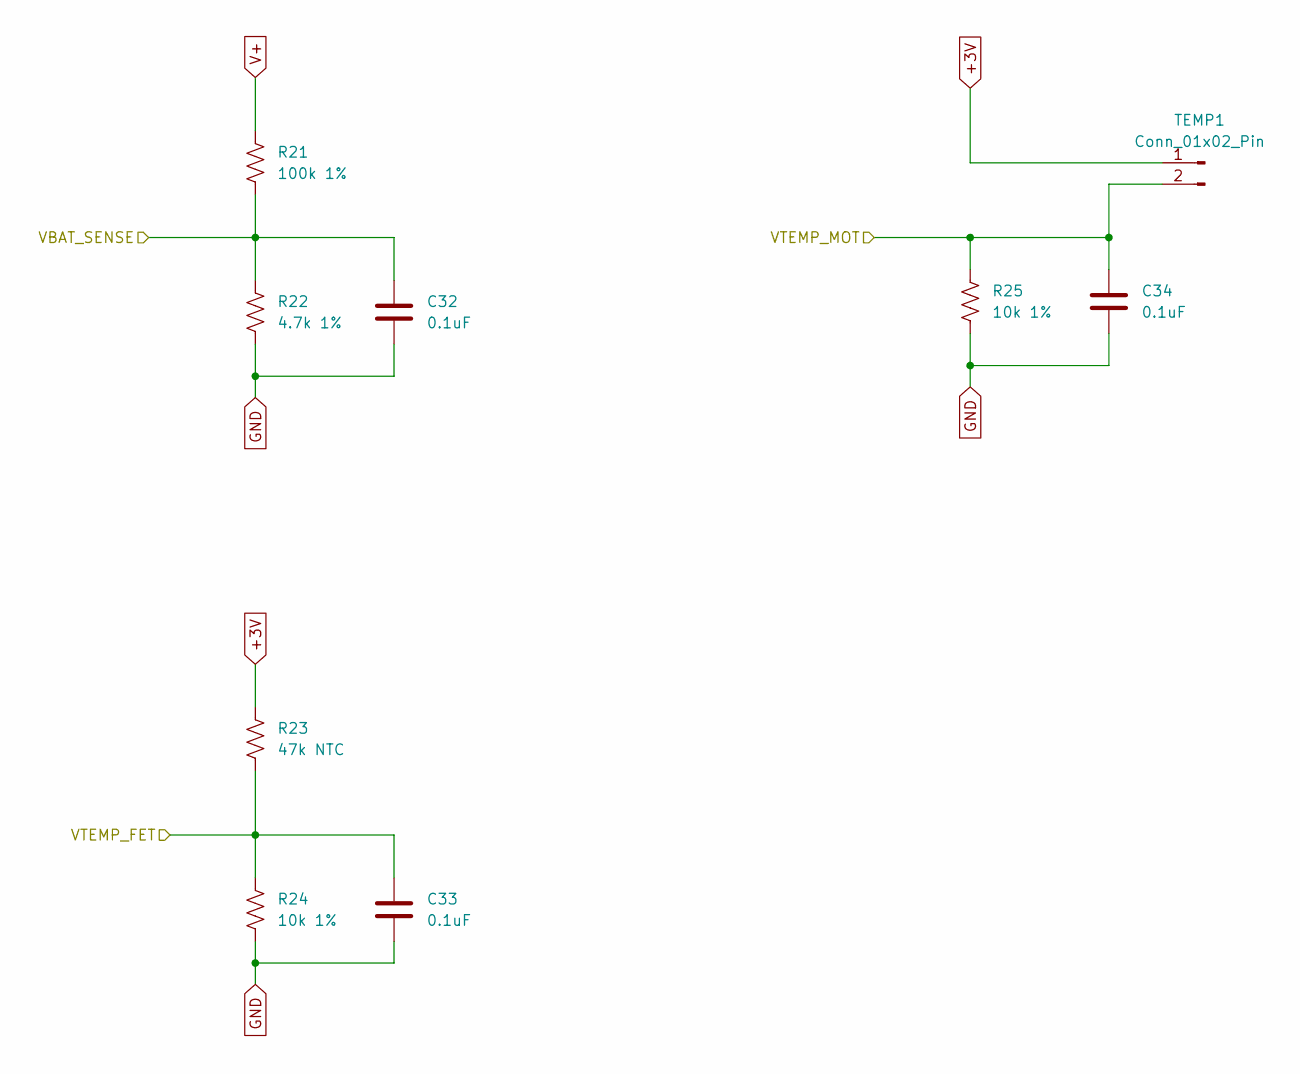
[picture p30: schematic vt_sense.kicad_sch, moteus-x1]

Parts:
C32, C33, C34: 0.1uF; C_0402_1005Metric; MPN MF-CAP-0402-0.1uF
R21: 100k 1%; R_0402_1005Metric; MPN RC0402FR-07100KL
R22: 4.7k 1%; R_0402_1005Metric; MPN RC0402FR-074K7L
R23: 47k NTC; R_0402_1005Metric; MPN NCP15WB473F03RC
R24, R25: 10k 1%; R_0402_1005Metric; MPN RC0402FR-0710KL
TEMP1: Conn_01x02_Pin; PinHeader_1x02_P2.54mm_Vertical

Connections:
+3V: R23.1, TEMP1.1; also elsewhere on the board
/VT Sense/VBAT_SENSE: C32.1, R21.2, R22.1; also elsewhere on the board
/VT Sense/VTEMP_FET: C33.1, R23.2, R24.1; also elsewhere on the board
/VT Sense/VTEMP_MOT: C34.1, R25.1, TEMP1.2; also elsewhere on the board
GND: C32.2, C33.2, C34.2, R22.2, R24.2, R25.2; also elsewhere on the board
V+: R21.1; also elsewhere on the board

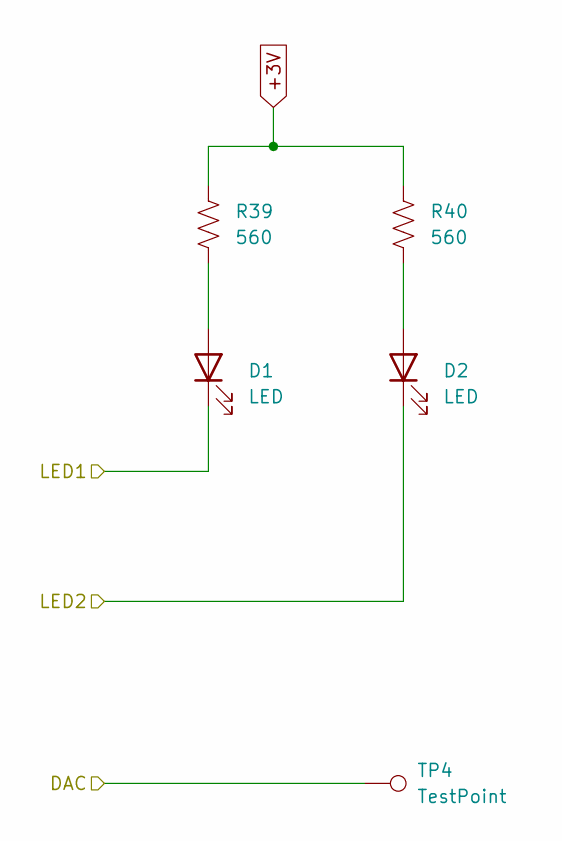
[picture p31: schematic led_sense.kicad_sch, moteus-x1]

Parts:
D1: LED; LED_0603_1608Metric; MPN MF-LED-0603-RED
D2: LED; LED_0603_1608Metric; MPN MF-LED-0603-GREEN
R39, R40: 560; R_0402_1005Metric; MPN MF-RES-0402-560
TP4: TestPoint; TestPoint_THTPad_D1.0mm_Drill0.5mm

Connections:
+3V: R39.1, R40.1; also elsewhere on the board
/LED Sense/DAC: TP4.1; also elsewhere on the board
/LED Sense/LED1: D1.1 (K); also elsewhere on the board
/LED Sense/LED2: D2.1 (K); also elsewhere on the board
unnamed: D1.2 (A), R39.2
unnamed: D2.2 (A), R40.2

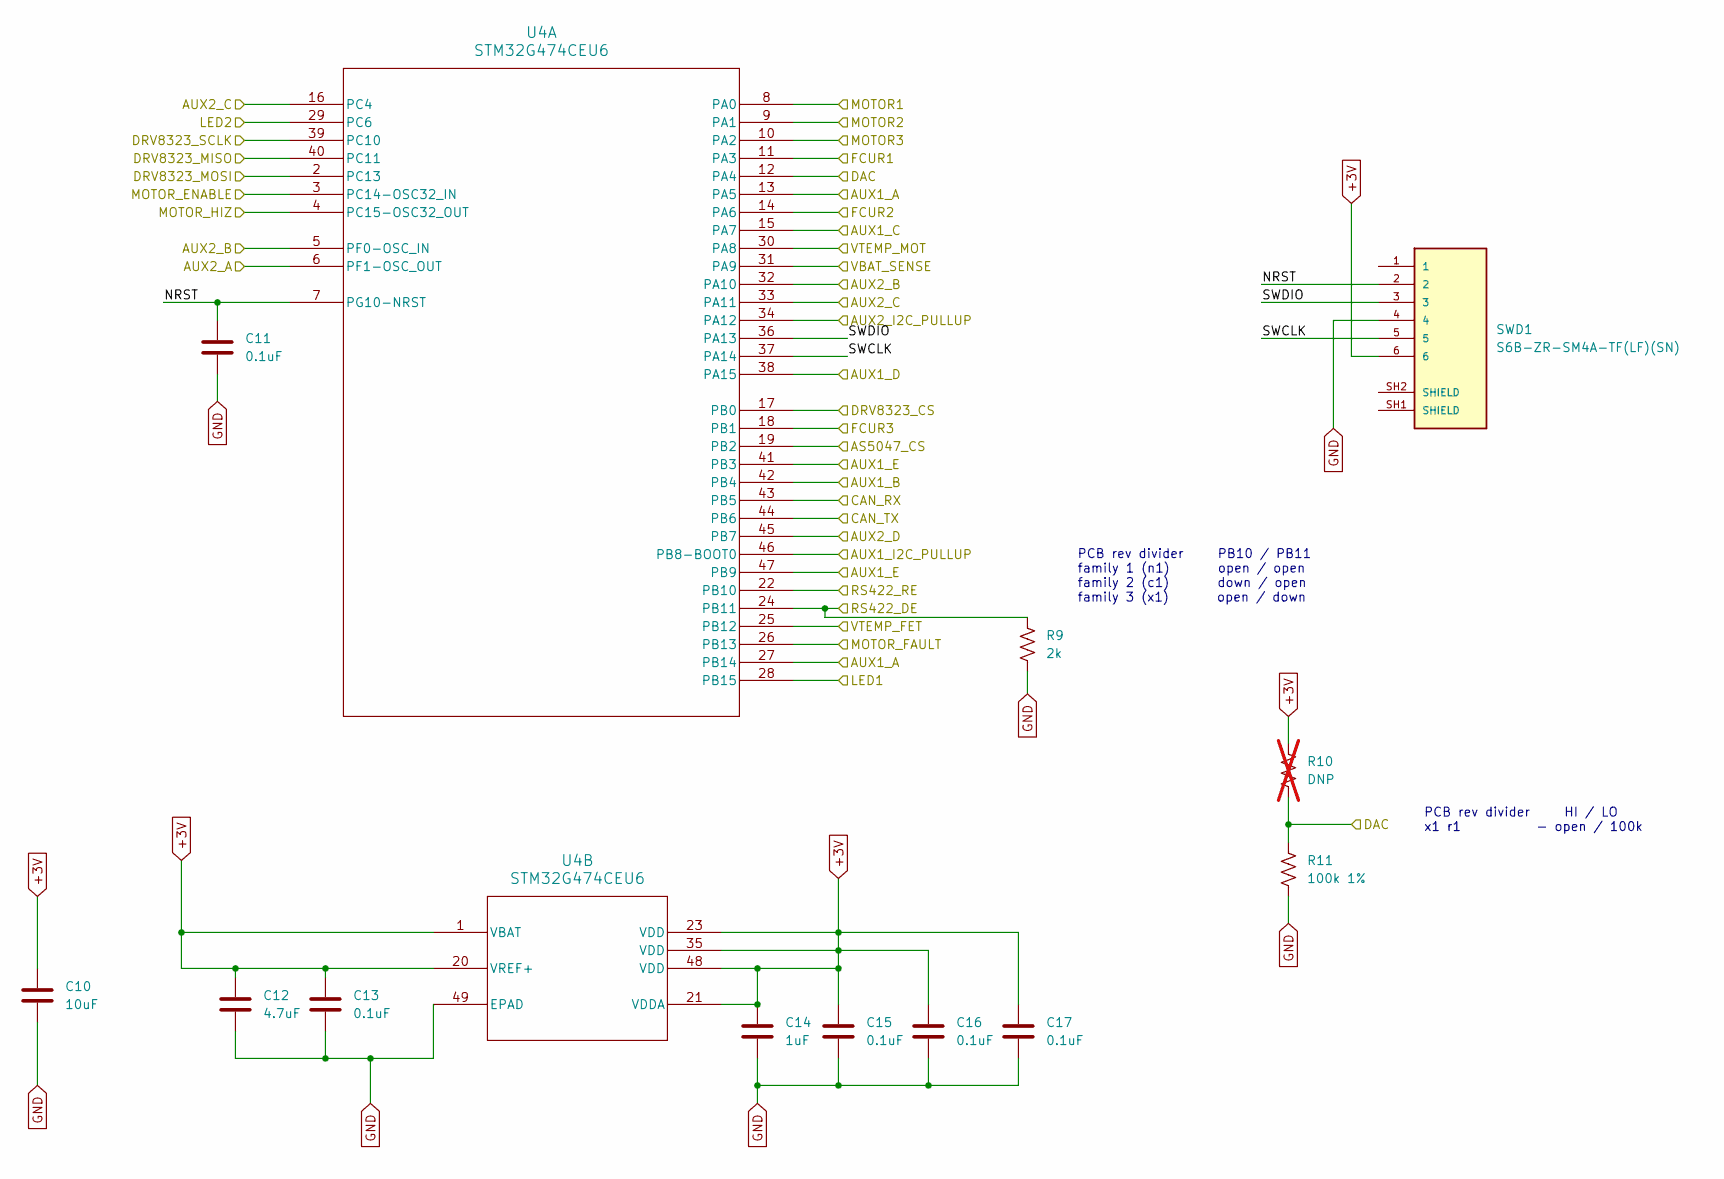
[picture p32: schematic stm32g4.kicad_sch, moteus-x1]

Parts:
C10: 10uF; C_1206_3216Metric; MPN MF-CAP-1206-10uF
C11, C13, C15, C16, C17: 0.1uF; C_0402_1005Metric; MPN MF-CAP-0402-0.1uF
C12: 4.7uF; C_0603_1608Metric; MPN CL10A475KP8NNNC
C14: 1uF; C_0402_1005Metric; MPN MF-CAP-0402-1uF
R9: 2k; R_0402_1005Metric; MPN MF-RES-0402-2K
R10: DNP; R_0402_1005Metric; not fitted
R11: 100k 1%; R_0402_1005Metric; MPN RC0402FR-07100KL
SWD1: S6B-ZR-SM4A-TF(LF)(SN); JST_S6B-ZR-SM4A-TF(LF)(SN); MPN S6B-ZR-SM4A-TF(LF)(SN)
U4: STM32G474CEU6; UFQFPN-48_7X7X0P55MM; MPN STM32G474CEU6

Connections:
+3V: C10.1, C12.1, C13.1, C14.1, C15.1, C16.1, C17.1, R10.1, SWD1.6, U4.1 (VBAT), U4.20 (VREF+), U4.21 (VDDA), U4.23 (VDD), U4.35 (VDD), U4.48 (VDD); also elsewhere on the board
/CAN/CAN_RX: U4.43 (PB5); also elsewhere on the board
/CAN/CAN_TX: U4.44 (PB6); also elsewhere on the board
/Current Sense/FCUR1: U4.11 (PA3); also elsewhere on the board
/Current Sense/FCUR2: U4.14 (PA6); also elsewhere on the board
/Current Sense/FCUR3: U4.18 (PB1); also elsewhere on the board
/Gate Driver/DRV8323_CS: U4.17 (PB0); also elsewhere on the board
/Gate Driver/DRV8323_FAULT: U4.26 (PB13); also elsewhere on the board
/Gate Driver/DRV8323_MISO: U4.40 (PC11); also elsewhere on the board
/Gate Driver/DRV8323_MOSI: U4.2 (PC13); also elsewhere on the board
/Gate Driver/DRV8323_SCLK: U4.39 (PC10); also elsewhere on the board
/Gate Driver/MOTOR1: U4.8 (PA0); also elsewhere on the board
/Gate Driver/MOTOR2: U4.9 (PA1); also elsewhere on the board
/Gate Driver/MOTOR3: U4.10 (PA2); also elsewhere on the board
/Gate Driver/MOTOR_ENABLE: U4.3 (PC14-OSC32_IN); also elsewhere on the board
/Gate Driver/MOTOR_HIZ: U4.4 (PC15-OSC32_OUT); also elsewhere on the board
/LED Sense/DAC: R10.2, R11.1, U4.12 (PA4); also elsewhere on the board
/LED Sense/LED1: U4.28 (PB15); also elsewhere on the board
/LED Sense/LED2: U4.29 (PC6); also elsewhere on the board
/VT Sense/VBAT_SENSE: U4.31 (PA9); also elsewhere on the board
/VT Sense/VTEMP_FET: U4.25 (PB12); also elsewhere on the board
/VT Sense/VTEMP_MOT: U4.30 (PA8); also elsewhere on the board
/aux1/AS5047_CS: U4.19 (PB2); also elsewhere on the board
/aux1/AUX1_A: U4.13 (PA5), U4.27 (PB14); also elsewhere on the board
/aux1/AUX1_B: U4.42 (PB4); also elsewhere on the board
/aux1/AUX1_C: U4.15 (PA7); also elsewhere on the board
/aux1/AUX1_D: U4.38 (PA15); also elsewhere on the board
/aux1/AUX1_E: U4.41 (PB3), U4.47 (PB9); also elsewhere on the board
/aux1/AUX1_I2C_PULLUP: U4.46 (PB8-BOOT0); also elsewhere on the board
/aux2/AUX2_A: U4.6 (PF1-OSC_OUT); also elsewhere on the board
/aux2/AUX2_B: U4.5 (PF0-OSC_IN), U4.32 (PA10); also elsewhere on the board
/aux2/AUX2_C: U4.16 (PC4), U4.33 (PA11); also elsewhere on the board
/aux2/AUX2_D: U4.45 (PB7); also elsewhere on the board
/aux2/AUX2_I2C_PULLUP: U4.34 (PA12); also elsewhere on the board
/rs422/RS422_DE: R9.1, U4.24 (PB11); also elsewhere on the board
/rs422/RS422_RE: U4.22 (PB10); also elsewhere on the board
/stm32g4/NRST: C11.1, SWD1.2, U4.7 (PG10-NRST)
/stm32g4/SWCLK: SWD1.5, U4.37 (PA14)
/stm32g4/SWDIO: SWD1.3, U4.36 (PA13)
GND: C10.2, C11.2, C12.2, C13.2, C14.2, C15.2, C16.2, C17.2, R9.2, R11.2, SWD1.4, U4.49 (EPAD); also elsewhere on the board

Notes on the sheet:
PCB rev divider HI / LO x1 r1 - open / 100k
PCB rev divider PB10 / PB11 family 1 (n1) open / open family 2 (c1) down / open family 3 (x1) open / down

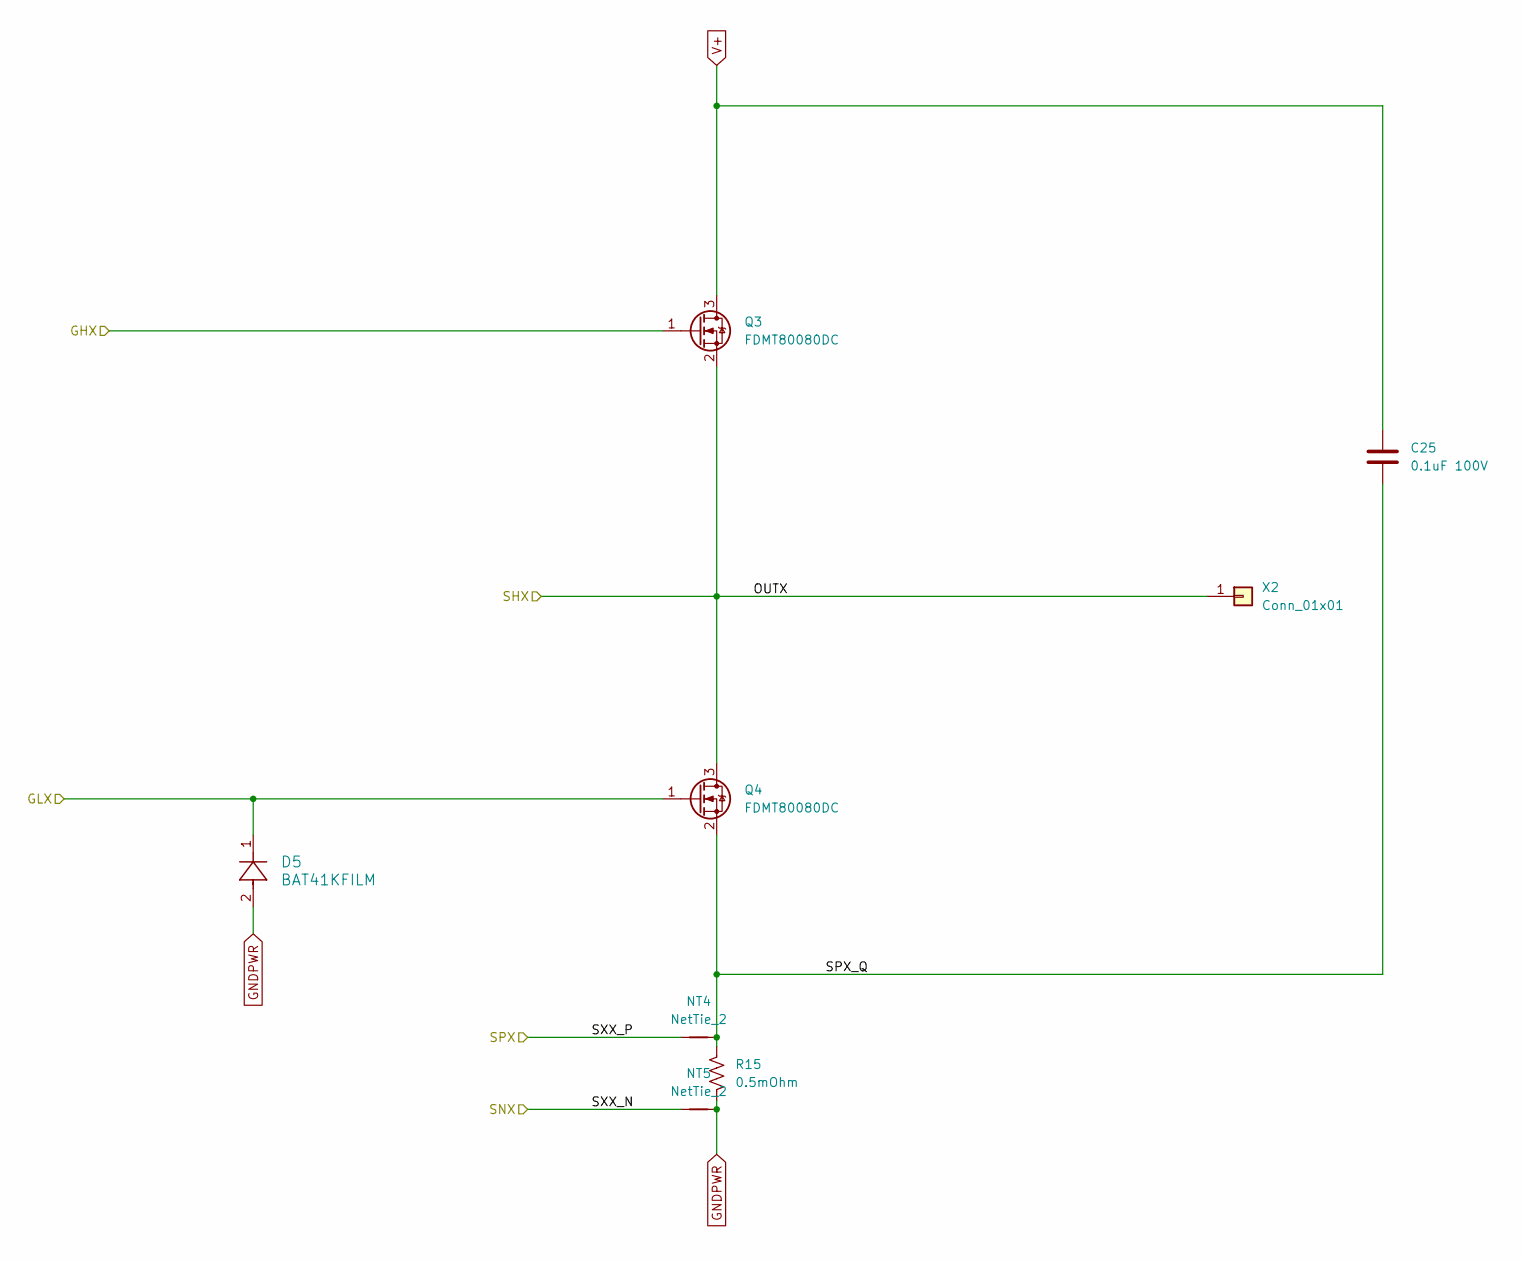
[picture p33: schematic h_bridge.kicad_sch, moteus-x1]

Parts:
C25: 0.1uF 100V; C_1812_4532Metric; MPN 18121C104MAT2A
D5: BAT41KFILM; SOD-523_STM; MPN BAT41KFILM
NT4, NT5: NetTie_2; NetTie-2_SMD_Pad0.2
Q3, Q4: FDMT80080DC; PQFN_8x8; MPN FDMT80080DC
R15: 0.5mOhm; R_2512_6332Metric; MPN WSLF2512L5000FEA
X2: Conn_01x01; POWER_M2.5

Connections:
/Gate Driver/GHB: Q3.1 (G); also elsewhere on the board
/Gate Driver/GLB: D5.1, Q4.1 (G); also elsewhere on the board
/H Bridge B/OUTX: Q3.2 (S), Q4.3 (D), X2.1; also elsewhere on the board
/H Bridge B/SPX_Q: C25.2, NT4.2, Q4.2 (S), R15.1
/H Bridge B/SXX_N: NT5.1; also elsewhere on the board
/H Bridge B/SXX_P: NT4.1; also elsewhere on the board
GNDPWR: D5.2, NT5.2, R15.2; also elsewhere on the board
V+: C25.1, Q3.3 (D); also elsewhere on the board

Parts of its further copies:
C24, C26: 0.1uF 100V; C_1812_4532Metric; MPN 18121C104MAT2A
D4, D6: BAT41KFILM; SOD-523_STM; MPN BAT41KFILM
NT2, NT3, NT6, NT7: NetTie_2; NetTie-2_SMD_Pad0.2
Q1, Q2, Q5, Q6: FDMT80080DC; PQFN_8x8; MPN FDMT80080DC
R14, R16: 0.5mOhm; R_2512_6332Metric; MPN WSLF2512L5000FEA
X1, X3: Conn_01x01; POWER_M2.5

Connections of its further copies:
/Gate Driver/GHA: Q1.1 (G); also elsewhere on the board
/Gate Driver/GHC: Q5.1 (G); also elsewhere on the board
/Gate Driver/GLA: D4.1, Q2.1 (G); also elsewhere on the board
/Gate Driver/GLC: D6.1, Q6.1 (G); also elsewhere on the board
/H Bridge A/OUTX: Q1.2 (S), Q2.3 (D), X1.1; also elsewhere on the board
/H Bridge A/SPX_Q: C24.2, NT2.2, Q2.2 (S), R14.1
/H Bridge A/SXX_N: NT3.1; also elsewhere on the board
/H Bridge A/SXX_P: NT2.1; also elsewhere on the board
/H Bridge C/OUTX: Q5.2 (S), Q6.3 (D), X3.1; also elsewhere on the board
/H Bridge C/SPX_Q: C26.2, NT6.2, Q6.2 (S), R16.1
/H Bridge C/SXX_N: NT7.1; also elsewhere on the board
/H Bridge C/SXX_P: NT6.1; also elsewhere on the board
GNDPWR: D4.2, D6.2, NT3.2, NT7.2, R14.2, R16.2; also elsewhere on the board
V+: C24.1, C26.1, Q1.3 (D), Q5.3 (D); also elsewhere on the board

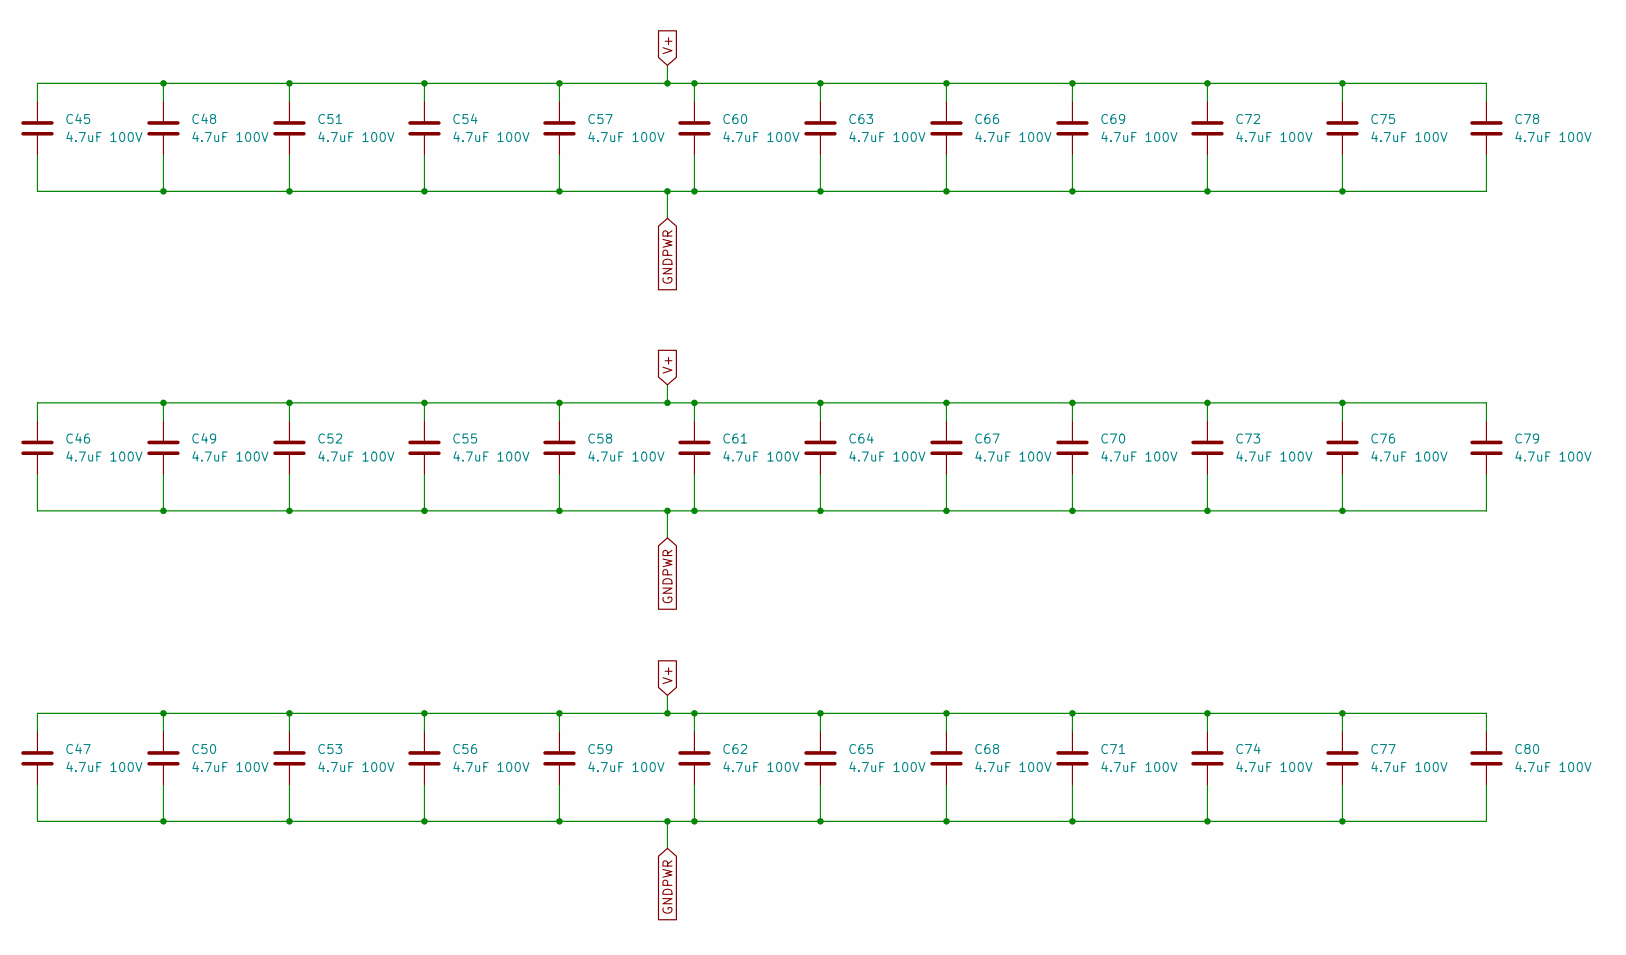
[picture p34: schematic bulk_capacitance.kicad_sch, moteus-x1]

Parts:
C45, C46, C47, C48, C49, C50, C51, C52, C53, C54, C55, C56, C57, C58, C59, C60, C61, C62, C63, C64, C65, C66, C67, C68, C69, C70, C71, C72, C73, C74, C75, C76, C77, C78, C79, C80: 4.7uF 100V; C_1206_3216Metric; MPN GRJ31CC72A475KE01K

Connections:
GNDPWR: C45.2, C46.2, C47.2, C48.2, C49.2, C50.2, C51.2, C52.2, C53.2, C54.2, C55.2, C56.2, C57.2, C58.2, C59.2, C60.2, C61.2, C62.2, C63.2, C64.2, C65.2, C66.2, C67.2, C68.2, C69.2, C70.2, C71.2, C72.2, C73.2, C74.2, C75.2, C76.2, C77.2, C78.2, C79.2, C80.2; also elsewhere on the board
V+: C45.1, C46.1, C47.1, C48.1, C49.1, C50.1, C51.1, C52.1, C53.1, C54.1, C55.1, C56.1, C57.1, C58.1, C59.1, C60.1, C61.1, C62.1, C63.1, C64.1, C65.1, C66.1, C67.1, C68.1, C69.1, C70.1, C71.1, C72.1, C73.1, C74.1, C75.1, C76.1, C77.1, C78.1, C79.1, C80.1; also elsewhere on the board

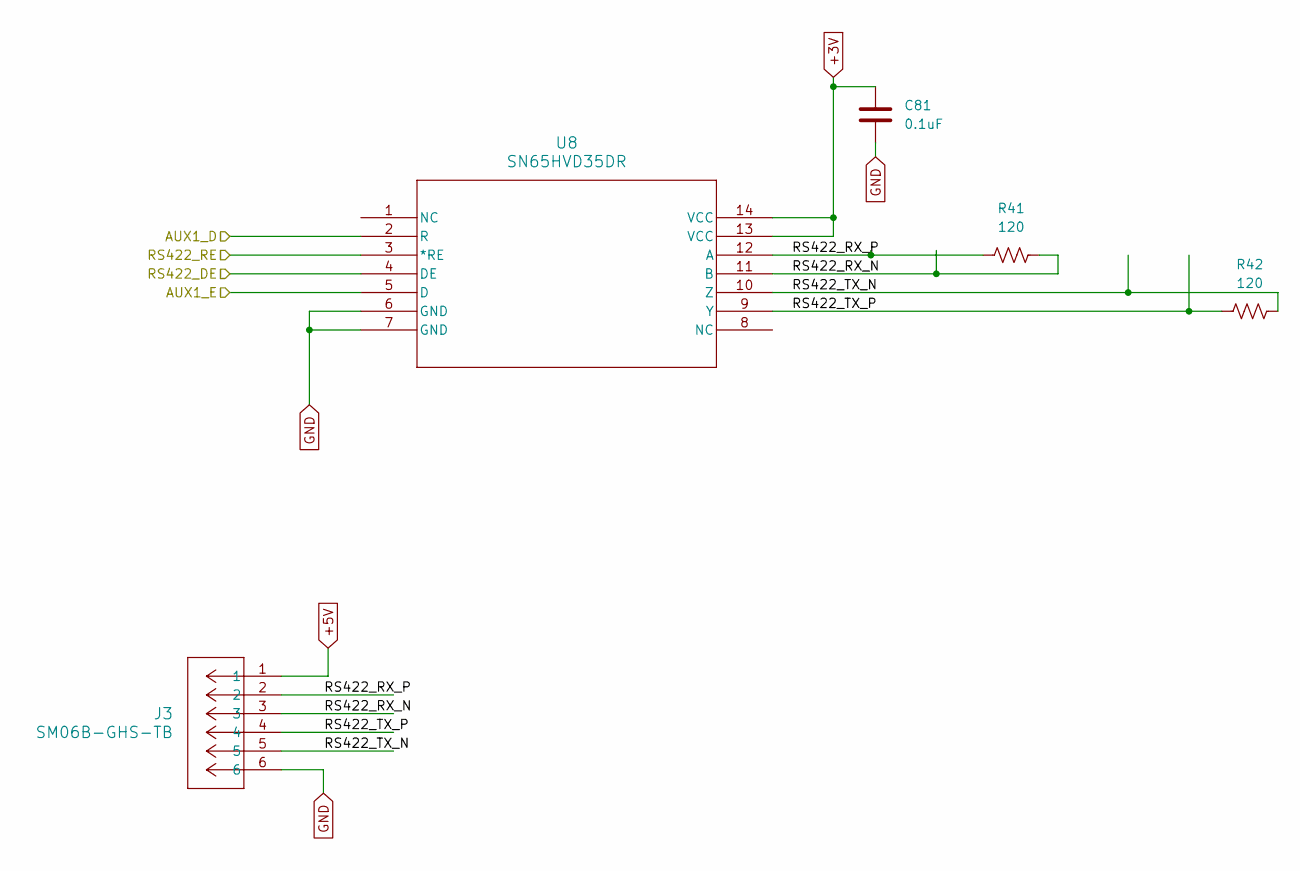
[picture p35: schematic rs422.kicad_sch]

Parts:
C81: 0.1uF; C_0402_1005Metric; MPN MF-CAP-0402-0.1uF
J3: SM06B-GHS-TB; CONN_SM06B-GHS-TB_JST; MPN SM06B-GHS-TB(LF)(SN)
R41, R42: 120; R_0402_1005Metric; MPN RC0402FR-07120RL
U8: SN65HVD35DR; D14; MPN SN65HVD35DR

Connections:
+3V: C81.1, U8.13 (VCC), U8.14 (VCC); also elsewhere on the board
+5V: J3.1; also elsewhere on the board
/aux1/AUX1_D: U8.2 (R); also elsewhere on the board
/aux1/AUX1_E: U8.5 (D); also elsewhere on the board
/rs422/RS422_DE: U8.4 (DE); also elsewhere on the board
/rs422/RS422_RE: U8.3 (*RE); also elsewhere on the board
/rs422/RS422_RX_N: J3.3, R41.2, U8.11 (B)
/rs422/RS422_RX_P: J3.2, R41.1, U8.12 (A)
/rs422/RS422_TX_N: J3.5, R42.2, U8.10 (Z)
/rs422/RS422_TX_P: J3.4, R42.1, U8.9 (Y)
GND: C81.2, J3.6, U8.6 (GND), U8.7 (GND); also elsewhere on the board

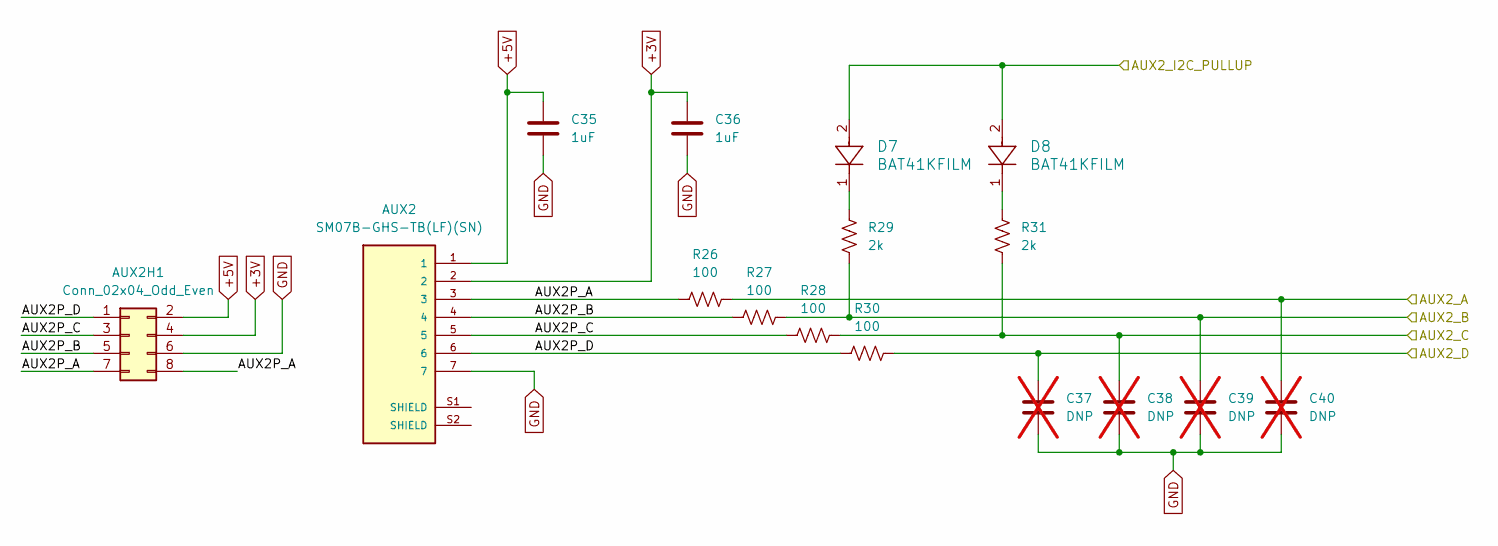
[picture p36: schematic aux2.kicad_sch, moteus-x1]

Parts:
AUX2: SM07B-GHS-TB(LF)(SN); JST_SM07B-GHS-TB(LF)(SN); MPN SM07B-GHS-TB(LF)(SN)
AUX2H1: Conn_02x04_Odd_Even; PinHeader_2x04_P1.27mm_Vertical
C35, C36: 1uF; C_0402_1005Metric; MPN MF-CAP-0402-1uF
C37, C38, C39, C40: DNP; C_0402_1005Metric; not fitted
D7, D8: BAT41KFILM; SOD-523_STM; MPN BAT41KFILM
R26, R27, R28, R30: 100; R_0402_1005Metric; MPN MF-RES-0402-100
R29, R31: 2k; R_0402_1005Metric; MPN MF-RES-0402-2K

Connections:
+3V: AUX2.2, AUX2H1.4, C36.1; also elsewhere on the board
+5V: AUX2.1, AUX2H1.2, C35.1; also elsewhere on the board
/aux2/AUX2P_A: AUX2.3, AUX2H1.7, AUX2H1.8, R26.1
/aux2/AUX2P_B: AUX2.4, AUX2H1.5, R27.1
/aux2/AUX2P_C: AUX2.5, AUX2H1.3, R28.1
/aux2/AUX2P_D: AUX2.6, AUX2H1.1, R30.1
/aux2/AUX2_A: C40.1, R26.2; also elsewhere on the board
/aux2/AUX2_B: C39.1, R27.2, R29.2; also elsewhere on the board
/aux2/AUX2_C: C38.1, R28.2, R31.2; also elsewhere on the board
/aux2/AUX2_D: C37.1, R30.2; also elsewhere on the board
/aux2/AUX2_I2C_PULLUP: D7.2, D8.2; also elsewhere on the board
GND: AUX2.7, AUX2H1.6, C35.2, C36.2, C37.2, C38.2, C39.2, C40.2; also elsewhere on the board
unnamed: D7.1, R29.1
unnamed: D8.1, R31.1

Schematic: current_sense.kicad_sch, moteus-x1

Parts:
C27, C28, C29: 1000pF; C_0402_1005Metric; MPN MF-CAP-0402-1nF
R17, R18, R19: 22; R_0402_1005Metric; MPN MF-RES-0402-22

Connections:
/Current Sense/CUR1: R17.1; also elsewhere on the board
/Current Sense/CUR2: R18.1; also elsewhere on the board
/Current Sense/CUR3: R19.1; also elsewhere on the board
/Current Sense/FCUR1: C27.1, R17.2; also elsewhere on the board
/Current Sense/FCUR2: C28.1, R18.2; also elsewhere on the board
/Current Sense/FCUR3: C29.1, R19.2; also elsewhere on the board
GND: C27.2, C28.2, C29.2; also elsewhere on the board

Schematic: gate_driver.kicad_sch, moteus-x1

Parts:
C18: 1uF; C_0603_1608Metric; MPN MF-CAP-0603-1uF
C19: 0.1uF 100V; C_0603_1608Metric; MPN GCJ188R72A104KA01D
C20: 1uF; C_0402_1005Metric; MPN MF-CAP-0402-1uF
C21: 1uF 25V; C_0603_1608Metric; MPN C1608X7R1E105K080AE
C22: 47nF 100V; C_0603_1608Metric; MPN C0603X473K1RAC7867
C23: 1uF; C_0603_1608Metric; MPN C1608X7R1E105K080AE
R12, R13: 2k; R_0402_1005Metric; MPN MF-RES-0402-2K
U5: DRV8353SRTAR; RTA0040B; MPN DRV8353SRTAR

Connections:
+3V: C18.2, R12.1, R13.1, U5.24 (VREF); also elsewhere on the board
+12V: C19.2, U5.3 (VM); also elsewhere on the board
/Current Sense/CUR1: U5.21 (SOC); also elsewhere on the board
/Current Sense/CUR2: U5.22 (SOB); also elsewhere on the board
/Current Sense/CUR3: U5.23 (SOA); also elsewhere on the board
/Gate Driver/CPH: C22.2, U5.2 (CPH)
/Gate Driver/CPL: C22.1, U5.1 (CPL)
/Gate Driver/DRV8323_CS: U5.30 (SCS_N); also elsewhere on the board
/Gate Driver/DRV8323_FAULT: R13.2, U5.26 (FAULT_N); also elsewhere on the board
/Gate Driver/DRV8323_MISO: R12.2, U5.27 (SDO); also elsewhere on the board
/Gate Driver/DRV8323_MOSI: U5.28 (SDI); also elsewhere on the board
/Gate Driver/DRV8323_SCLK: U5.29 (SCLK); also elsewhere on the board
/Gate Driver/GHA: U5.6 (GHA); also elsewhere on the board
/Gate Driver/GHB: U5.15 (GHB); also elsewhere on the board
/Gate Driver/GHC: U5.16 (GHC); also elsewhere on the board
/Gate Driver/GLA: U5.8 (GLA); also elsewhere on the board
/Gate Driver/GLB: U5.13 (GLB); also elsewhere on the board
/Gate Driver/GLC: U5.18 (GLC); also elsewhere on the board
/Gate Driver/MOTOR1: U5.32 (INHA); also elsewhere on the board
/Gate Driver/MOTOR2: U5.34 (INHB); also elsewhere on the board
/Gate Driver/MOTOR3: U5.36 (INHC); also elsewhere on the board
/Gate Driver/MOTOR_ENABLE: U5.31 (ENABLE); also elsewhere on the board
/Gate Driver/MOTOR_HIZ: U5.33 (INLA), U5.35 (INLB), U5.37 (INLC); also elsewhere on the board
/H Bridge A/OUTX: U5.7 (SHA); also elsewhere on the board
/H Bridge A/SXX_N: U5.10 (SNA); also elsewhere on the board
/H Bridge A/SXX_P: U5.9 (SPA); also elsewhere on the board
/H Bridge B/OUTX: U5.14 (SHB); also elsewhere on the board
/H Bridge B/SXX_N: U5.11 (SNB); also elsewhere on the board
/H Bridge B/SXX_P: U5.12 (SPB); also elsewhere on the board
/H Bridge C/OUTX: U5.17 (SHC); also elsewhere on the board
/H Bridge C/SXX_N: U5.20 (SNC); also elsewhere on the board
/H Bridge C/SXX_P: U5.19 (SPC); also elsewhere on the board
GND: C18.1, C20.1, C23.1, U5.25 (AGND); also elsewhere on the board
GNDPWR: C19.1, U5.39 (PGND), U5.41 (PAD); also elsewhere on the board
unnamed: C20.2, U5.38 (DVDD)
unnamed: C21.2, U5.5 (VCP)
unnamed: C23.2, U5.40 (VGLS)
V+: C21.1, U5.4 (VDRAIN); also elsewhere on the board

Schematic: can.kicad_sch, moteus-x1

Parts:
C30, C31: 0.1uF; C_0402_1005Metric; MPN MF-CAP-0402-0.1uF
CAN1, CAN2: S3B-PH-SM4-TB(LF)(SN); JST_S3B-PH-SM4-TB(LF)(SN); MPN S3B-PH-SM4-TB(LF)(SN)
CAN_DBG1: Conn_01x03_Pin; PinHeader_1x03_P2.00mm_Vertical
R20: 120; R_0603_1608Metric; not fitted
U6: TCAN1057AEV-Q1; SOIC-8_3.9x4.9mm_P1.27mm; MPN TCAN1057AEVDRQ1

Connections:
+3V: C30.1, U6.5 (VIO); also elsewhere on the board
+5V: C31.1, U6.3 (VCC); also elsewhere on the board
/CAN/CAN_N: CAN1.2, CAN2.2, CAN_DBG1.2, R20.2, U6.6 (CANL)
/CAN/CAN_P: CAN1.1, CAN2.1, CAN_DBG1.1, R20.1, U6.7 (CANH)
/CAN/CAN_RX: U6.4 (RXD); also elsewhere on the board
/CAN/CAN_TX: U6.1 (TXD); also elsewhere on the board
GND: C30.2, C31.2, CAN1.3, CAN2.3, CAN_DBG1.3, U6.2 (GND), U6.8 (STB), U6.9 (PAD); also elsewhere on the board

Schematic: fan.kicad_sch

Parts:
C82: 4.7uF; C_1206_3216Metric; MPN GRJ31CC72A475KE01K
FAN1: Conn_01x04_Pin; PinSocket_2x02_P2.54mm_Vertical
R43, R44: 100; R_0402_1005Metric; MPN MF-RES-0402-100

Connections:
+12V: C82.1, FAN1.2; also elsewhere on the board
/aux2/AUX2_C: R43.1; also elsewhere on the board
/aux2/AUX2_D: R44.1; also elsewhere on the board
GND: C82.2, FAN1.1; also elsewhere on the board
unnamed: FAN1.3, R44.2
unnamed: FAN1.4, R43.2

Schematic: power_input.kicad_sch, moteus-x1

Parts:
C1: 1uF 100V; C_0805_2012Metric; MPN GCM21BC72A105KE36L
C2: 0.1uF 100V; C_0603_1608Metric; MPN GCJ188R72A104KA01D
C3, C6: 1uF; C_0402_1005Metric; MPN MF-CAP-0402-1uF
C4, C7, C9: 22uF; C_1210_3225Metric; MPN GRM32ER71E226KE15L
C5: 5600pF; C_0402_1005Metric; MPN GCM155R71E562KA37D
C8: DNP; C_0402_1005Metric; not fitted
D3: SMBJ51D-M3/I; D_SMB; MPN SMBJ51D-M3/I
D13: US1B; D_SMA; MPN STPS1H100A
J1: XT30PW-M; AMASS_XT30PW-M; MPN XT30PW-M
J4: Conn_01x02_Pin; PinHeader_1x02_P2.00mm_Vertical
L1, L3: 2.2uH; IND_DFE252012_MUR; MPN DFE252012PD-2R2M=P2
L2: 100uH; IND_6028-WE-LQS_WRE; MPN 74404063101
M1, M2, M3, M4: Conn_01x01_Pin; M3_MOUNT_CORNER
NT1: NetTie_2; NetTie-2_SMD_Pad0.254mm
R1: 42.2k 1%; R_0402_1005Metric; MPN RC0402FR-0742K2L
R2: 69.8k 1%; R_0402_1005Metric; MPN RC0402FR-0769K8L
R3: 80.6k 1%; R_0402_1005Metric; MPN RC0402FR-0780K6L
R4: 22; R_0402_1005Metric; MPN MF-RES-0402-22
R5: 52.3k 1%; R_0402_1005Metric; MPN RC0402FR-0752K3L
R6: 226k 1%; R_0402_1005Metric; MPN RC0402FR-07226KL
R7: 16.2k 1%; R_0402_1005Metric; MPN RC0402FR-0716K2L
R8: DNP; R_0402_1005Metric; not fitted
TP1, TP2, TP3: TestPoint; TestPoint_THTPad_D1.5mm_Drill0.7mm
U1: MAX17760ATC+; 21-0664E_1233-1C_MXM; MPN MAX17760ATC+
U2, U3: TPS629203DRLR; SOT-5x3_DRL0008A_TEX; MPN TPS629203DRLR
VN1: Conn_01x01; POWER_M2.5
VP1: Conn_01x01; POWER_M2.5

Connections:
+3V: C9.1, L3.1, TP3.1, U3.3 (VOS); also elsewhere on the board
+5V: C4.1, D13.1 (K), L1.1, TP1.1, U2.3 (VOS), U3.6 (VIN), U3.7 (EN); also elsewhere on the board
+12V: C7.1, L2.1, R4.2, R6.1, TP2.1, U2.6 (VIN), U2.7 (EN); also elsewhere on the board
/Power Input/5V_IN: D13.2 (A), J4.1
GND: C4.2, C6.2, C7.2, C9.2, J4.2, NT1.2, R1.2, R3.2, R5.2, R7.2, U2.5 (GND), U3.5 (GND); also elsewhere on the board
GNDPWR: C1.2, C2.2, C3.2, C5.2, C8.2, D3.2 (A2), J1.N, NT1.1, R2.2, R8.2, U1.2 (PGND), U1.10 (MODE), U1.11 (SGND), U1.13 (EPAD), VN1.1; also elsewhere on the board
MOUNT_GND: C8.1, M4.1, R8.1
unnamed: C6.1, R4.1, U1.7 (EXTVCC)
unnamed: R6.2, R7.1, U1.8 (FB)
unnamed: L2.2, U1.12 (LX)
unnamed: R2.1, U1.6 (RT/SYNC)
unnamed: C5.1, U1.9 (SS)
unnamed: C3.1, U1.3 (VCC)
unnamed: R3.1, U2.1 (FB/VSET)
unnamed: R1.1, U2.8 (MODE/S-CONF)
unnamed: L1.2, U2.4 (SW)
unnamed: R5.1, U3.8 (MODE/S-CONF)
unnamed: L3.2, U3.4 (SW)
V+: C1.1, C2.1, D3.1 (A1), J1.P, U1.1 (VIN), VP1.1; also elsewhere on the board

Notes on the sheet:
FB: VSET FSW: 2.5MHz Output Discharge: No Mode: Auto PFM
FB: VSET FSW: 2.5MHz Output Discharge: No Mode: FPWM
0.9ms soft start
OPEN = 3.3V
400kHz

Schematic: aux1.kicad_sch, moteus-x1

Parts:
AUX1: SM08B-GHS-TB; CONN_SM08B-GHS-TB_JST; MPN SM08B-GHS-TB(LF)(SN)
AUX1_S1: Conn_01x04; PinHeader_1x04_P1.27mm_Vertical
C41, C42, C43: 1uF; C_0402_1005Metric; MPN MF-CAP-0402-1uF
C44: 0.1uF; C_0402_1005Metric; MPN MF-CAP-0402-0.1uF
D9, D10: BAT41KFILM; SOD-523_STM; MPN BAT41KFILM
R32, R33, R34, R35, R36: 100; R_0402_1005Metric; MPN MF-RES-0402-100
R37, R38: 2k; R_0402_1005Metric; MPN MF-RES-0402-2K
U7: MA600; QFN-16-1EP_3x3mm_P0.5mm_EP1.75x1.75mm; MPN MA600GQE-0000

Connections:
+3V: AUX1.2, AUX1_S1.1, C42.1, C43.1, C44.1, U7.13 (VDD), U7.14 (AVDD); also elsewhere on the board
+5V: AUX1.1, C41.1; also elsewhere on the board
/aux1/AS5047_CS: U7.5 (~CS); also elsewhere on the board
/aux1/AUX1P_A: AUX1.3, R32.1
/aux1/AUX1P_B: AUX1.4, R33.1
/aux1/AUX1P_C: AUX1.5, R34.1
/aux1/AUX1P_D: AUX1.6, AUX1_S1.2, R35.1
/aux1/AUX1P_E: AUX1.7, AUX1_S1.3, R36.1
/aux1/AUX1_A: R32.2, U7.12 (SCLK); also elsewhere on the board
/aux1/AUX1_B: R33.2, U7.7 (MISO); also elsewhere on the board
/aux1/AUX1_C: R34.2, U7.4 (MOSI); also elsewhere on the board
/aux1/AUX1_D: R35.2, R37.2; also elsewhere on the board
/aux1/AUX1_E: R36.2, R38.2; also elsewhere on the board
/aux1/AUX1_I2C_PULLUP: D9.2, D10.2; also elsewhere on the board
GND: AUX1.8, AUX1_S1.4, C41.2, C42.2, C43.2, C44.2, U7.8 (GND), U7.10 (TEST); also elsewhere on the board
unnamed: D9.1, R37.1
unnamed: D10.1, R38.1

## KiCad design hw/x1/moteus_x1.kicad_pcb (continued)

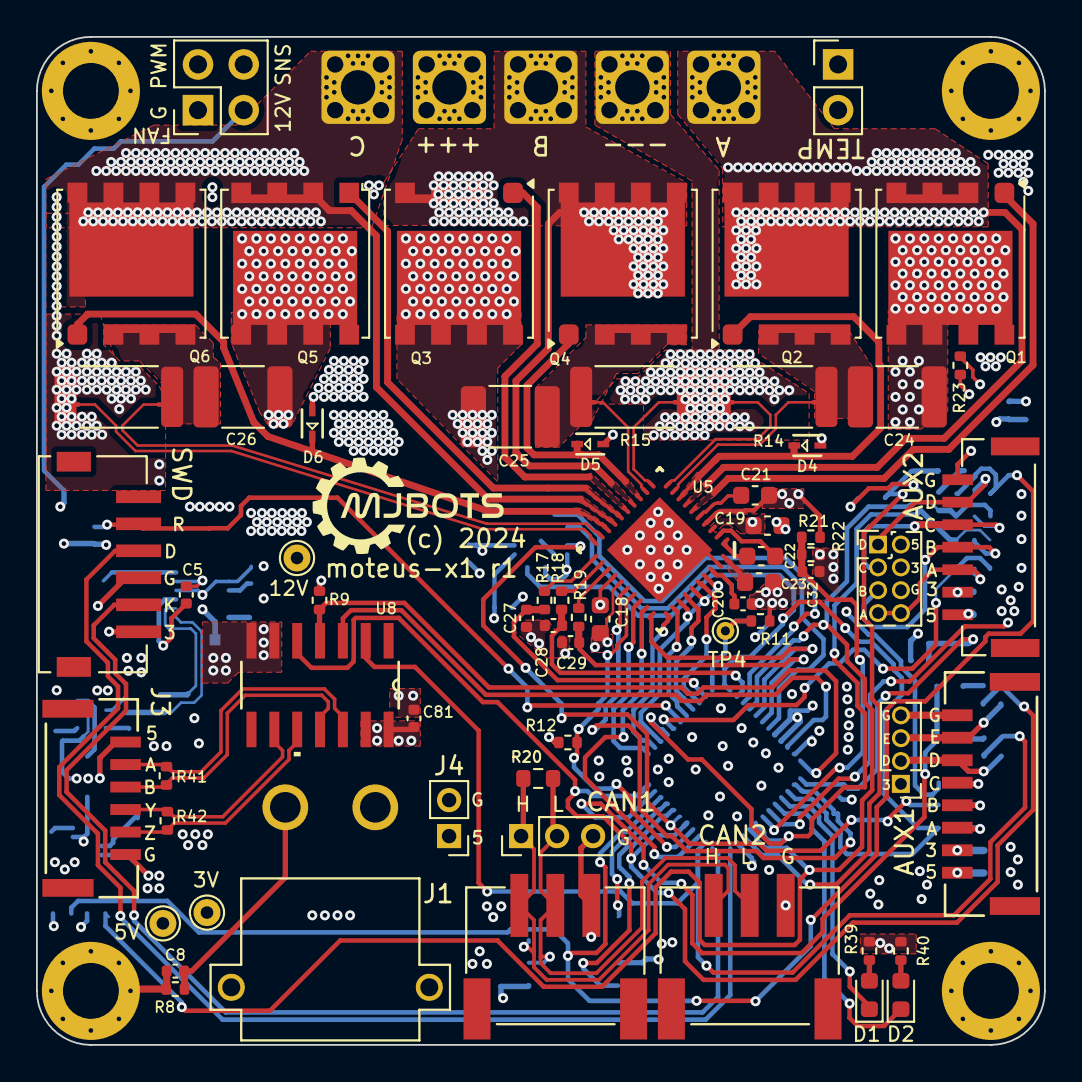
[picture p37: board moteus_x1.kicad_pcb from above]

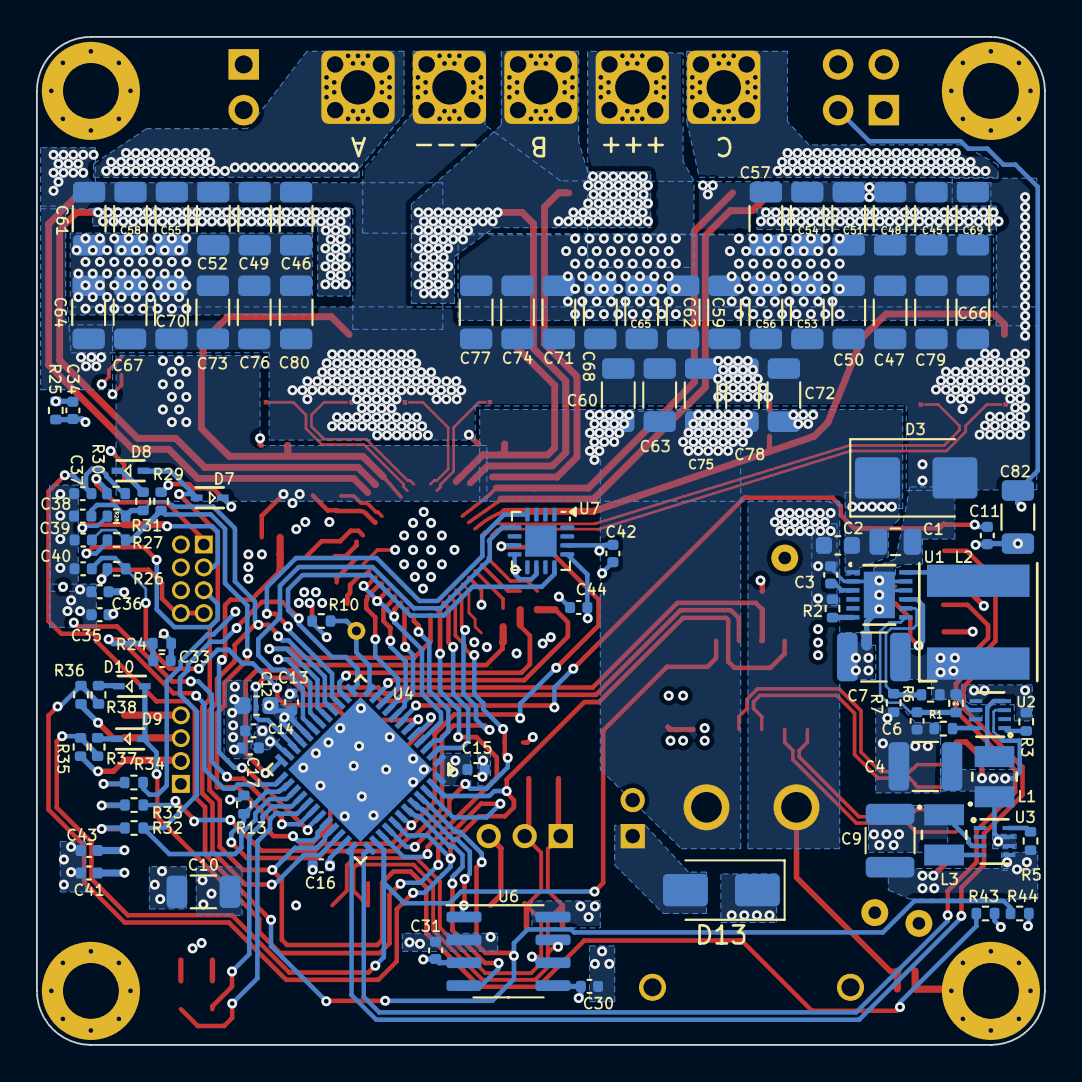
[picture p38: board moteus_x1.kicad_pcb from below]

Board: 6 copper layers, 56.0 x 56.0 mm, 187 parts (108 on the bottom side), 106 nets.

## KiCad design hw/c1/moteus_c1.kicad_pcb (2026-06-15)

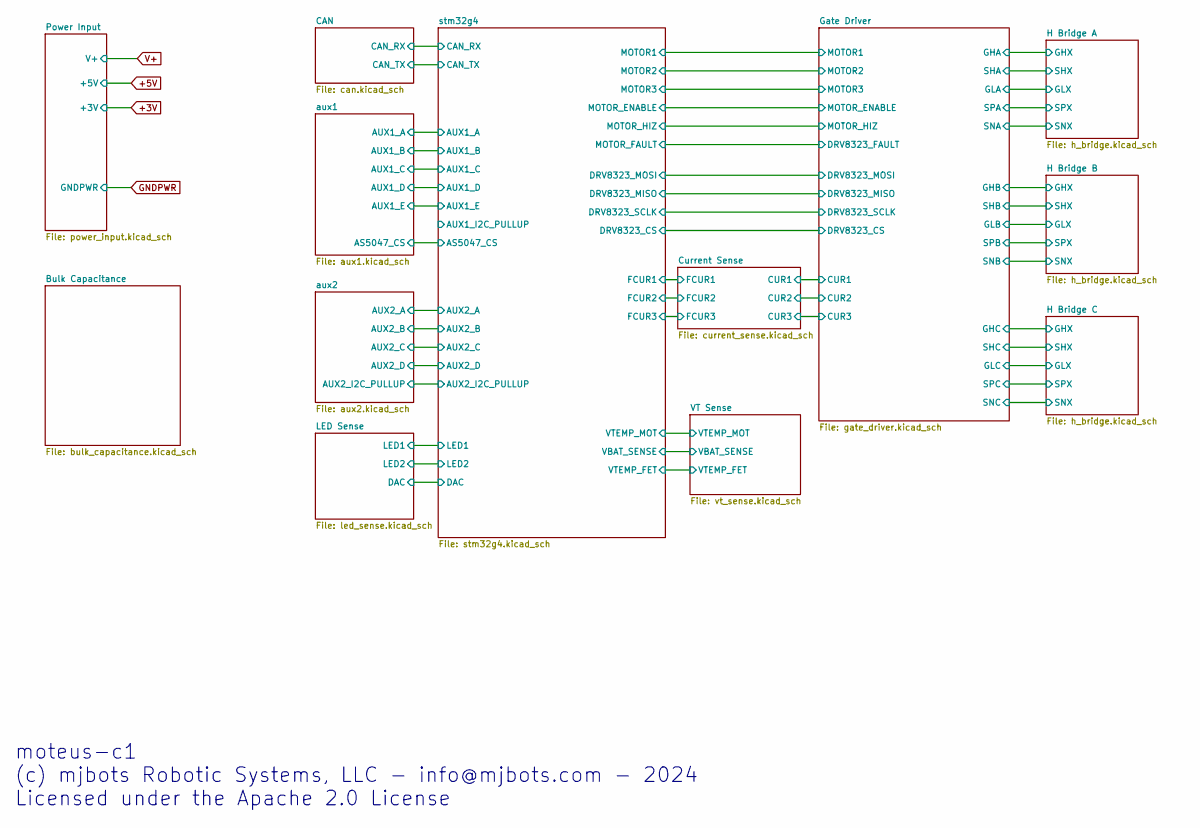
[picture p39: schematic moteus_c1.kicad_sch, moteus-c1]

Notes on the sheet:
moteus-c1 (c) mjbots Robotic Systems, LLC - info@mjbots.com - 2024 Licensed under the Apache 2.0 License

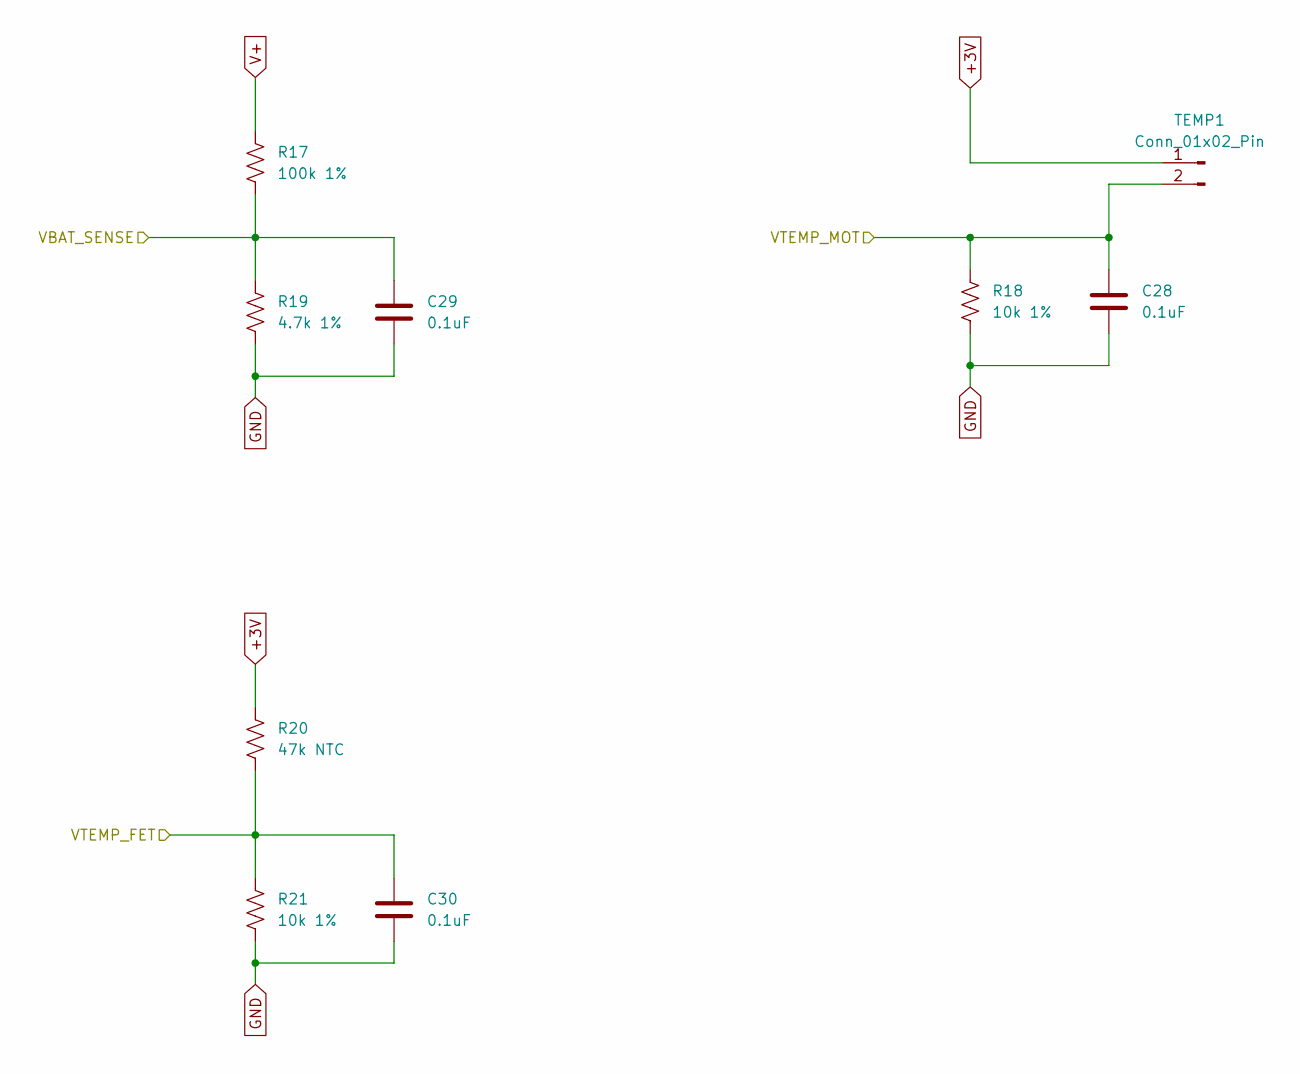
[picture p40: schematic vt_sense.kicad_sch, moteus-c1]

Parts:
C28, C29, C30: 0.1uF; C_0402_1005Metric; MPN MF-CAP-0402-0.1uF
R17: 100k 1%; R_0402_1005Metric; MPN RC0402FR-07100KL
R18, R21: 10k 1%; R_0402_1005Metric; MPN RC0402FR-0710KL
R19: 4.7k 1%; R_0402_1005Metric; MPN RC0402FR-074K7L
R20: 47k NTC; R_0402_1005Metric; MPN NCP15WB473F03RC
TEMP1: Conn_01x02_Pin; PinHeader_1x02_P2.00mm_Vertical

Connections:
/VT Sense/VBAT_SENSE: C29.1, R17.2, R19.1; also elsewhere on the board
/VT Sense/VTEMP_FET: C30.1, R20.2, R21.1; also elsewhere on the board
/VT Sense/VTEMP_MOT: C28.1, R18.1, TEMP1.2; also elsewhere on the board
V+: R17.1; also elsewhere on the board


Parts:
D13: LED; LED_0603_1608Metric; MPN MF-LED-0603-RED
D14: LED; LED_0603_1608Metric; MPN MF-LED-0603-GREEN
R29, R30: 560; R_0402_1005Metric; MPN MF-RES-0402-560
TP1: TestPoint; TestPoint_THTPad_D1.0mm_Drill0.5mm

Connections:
/LED Sense/LED1: D13.1 (K); also elsewhere on the board
/LED Sense/LED2: D14.1 (K); also elsewhere on the board
unnamed: D13.2 (A), R29.2
unnamed: D14.2 (A), R30.2


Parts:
C6, C9, C11, C12, C13: 0.1uF; C_0402_1005Metric; MPN MF-CAP-0402-0.1uF
C7: 10uF; C_1206_3216Metric; MPN MF-CAP-1206-10uF
C8: 4.7uF; C_0603_1608Metric; MPN CL10A475KP8NNNC
C10: 1uF; C_0402_1005Metric; MPN MF-CAP-0402-1uF
R2: 2k; R_0402_1005Metric; MPN MF-RES-0402-2K
SWD1: S6B-ZR-SM4A-TF(LF)(SN); JST_S6B-ZR-SM4A-TF(LF)(SN); MPN S6B-ZR-SM4A-TF(LF)(SN)
U3: STM32G474CEU6; UFQFPN-48_7X7X0P55MM; MPN STM32G474CEU6

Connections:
/CAN/CAN_RX: U3.43 (PB5); also elsewhere on the board
/CAN/CAN_TX: U3.44 (PB6); also elsewhere on the board
/Current Sense/FCUR1: U3.11 (PA3); also elsewhere on the board
/Current Sense/FCUR2: U3.14 (PA6); also elsewhere on the board
/Current Sense/FCUR3: U3.18 (PB1); also elsewhere on the board
/Gate Driver/DRV8323_CS: U3.17 (PB0); also elsewhere on the board
/Gate Driver/DRV8323_FAULT: U3.26 (PB13); also elsewhere on the board
/Gate Driver/DRV8323_MOSI: U3.2 (PC13); also elsewhere on the board
/Gate Driver/DRV8323_SCLK: U3.39 (PC10); also elsewhere on the board
/Gate Driver/MOTOR1: U3.8 (PA0); also elsewhere on the board
/Gate Driver/MOTOR2: U3.9 (PA1); also elsewhere on the board
/Gate Driver/MOTOR3: U3.10 (PA2); also elsewhere on the board
/Gate Driver/MOTOR_ENABLE: U3.3 (PC14-OSC32_IN); also elsewhere on the board
/Gate Driver/MOTOR_HIZ: U3.4 (PC15-OSC32_OUT); also elsewhere on the board
/LED Sense/LED1: U3.28 (PB15); also elsewhere on the board
/LED Sense/LED2: U3.29 (PC6); also elsewhere on the board
/VT Sense/VBAT_SENSE: U3.31 (PA9); also elsewhere on the board
/VT Sense/VTEMP_FET: U3.25 (PB12); also elsewhere on the board
/VT Sense/VTEMP_MOT: U3.30 (PA8); also elsewhere on the board
/aux1/AS5047_CS: U3.19 (PB2); also elsewhere on the board
/aux1/AUX1_A: U3.13 (PA5); also elsewhere on the board
/aux1/AUX1_B: U3.42 (PB4); also elsewhere on the board
/aux1/AUX1_C: U3.15 (PA7); also elsewhere on the board
/aux1/AUX1_D: U3.38 (PA15); also elsewhere on the board
/aux1/AUX1_E: U3.41 (PB3), U3.47 (PB9); also elsewhere on the board
/aux2/AUX2_A: U3.6 (PF1-OSC_OUT); also elsewhere on the board
/aux2/AUX2_B: U3.5 (PF0-OSC_IN), U3.32 (PA10); also elsewhere on the board
/aux2/AUX2_C: U3.16 (PC4), U3.33 (PA11); also elsewhere on the board
/aux2/AUX2_D: U3.45 (PB7); also elsewhere on the board
/aux2/AUX2_I2C_PULLUP: U3.34 (PA12); also elsewhere on the board
/stm32g4/AUX1_I2C_PULLUP: U3.46 (PB8-BOOT0)
/stm32g4/NRST: C6.1, SWD1.2, U3.7 (PG10-NRST)
/stm32g4/SWCLK: SWD1.5, U3.37 (PA14)
/stm32g4/SWDIO: SWD1.3, U3.36 (PA13)

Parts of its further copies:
R31: 2k; R_0402_1005Metric; MPN MF-RES-0402-2K

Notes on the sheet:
PB10 is disconnected on r4.5/r4.8/r4.11 PB10 is RS422 receive enable output on n1 It is tied to ground here to detect we are a c1 board
PCB rev divider HI / LO r1.0 - open / open (should not have been all open) r1.1 - open / 100k
AUX1_A (but only for external)


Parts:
C19: 0.1uF 100V; C_1206_3216Metric; MPN 12061C104KAT2A
D4: BAT41KFILM; SOD-523_STM; MPN BAT41KFILM
NT2, NT3: NetTie_2; NetTie-2_SMD_Pad0.2
Q1, Q2: TPN19008QM_LQ; TSON Advance_TOS; MPN TPN19008QM,LQ
R6: 2mOhm; R_0805_2012Metric; MPN CSSH0805FT2L00
X1: Conn_01x01; POWER_M2.5

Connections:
/Gate Driver/GHA: Q1.4 (GATE); also elsewhere on the board
/Gate Driver/GLA: D4.1, Q2.4 (GATE); also elsewhere on the board
/H Bridge A/OUTX: Q1.1 (SOURCE), Q1.2 (SOURCE), Q1.3 (SOURCE), Q2.5 (DRAIN), Q2.6 (DRAIN), Q2.7 (DRAIN), Q2.8 (DRAIN), X1.1; also elsewhere on the board
/H Bridge A/SPX_Q: C19.2, NT2.2, Q2.1 (SOURCE), Q2.2 (SOURCE), Q2.3 (SOURCE), R6.1
/H Bridge A/SXX_N: NT3.1; also elsewhere on the board
/H Bridge A/SXX_P: NT2.1; also elsewhere on the board
GNDPWR: D4.2, NT3.2, R6.2; also elsewhere on the board
V+: C19.1, Q1.5 (DRAIN), Q1.6 (DRAIN), Q1.7 (DRAIN), Q1.8 (DRAIN); also elsewhere on the board

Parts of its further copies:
C20, C21: 0.1uF 100V; C_1206_3216Metric; MPN 12061C104KAT2A
D7, D10: BAT41KFILM; SOD-523_STM; MPN BAT41KFILM
NT4, NT5, NT6, NT7: NetTie_2; NetTie-2_SMD_Pad0.2
Q3, Q4, Q5, Q6: TPN19008QM_LQ; TSON Advance_TOS; MPN TPN19008QM,LQ
R9, R12: 2mOhm; R_0805_2012Metric; MPN CSSH0805FT2L00
X2, X3: Conn_01x01; POWER_M2.5

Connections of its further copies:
/Gate Driver/GHB: Q3.4 (GATE); also elsewhere on the board
/Gate Driver/GHC: Q5.4 (GATE); also elsewhere on the board
/Gate Driver/GLB: D7.1, Q4.4 (GATE); also elsewhere on the board
/Gate Driver/GLC: D10.1, Q6.4 (GATE); also elsewhere on the board
/H Bridge B/OUTX: Q3.1 (SOURCE), Q3.2 (SOURCE), Q3.3 (SOURCE), Q4.5 (DRAIN), Q4.6 (DRAIN), Q4.7 (DRAIN), Q4.8 (DRAIN), X2.1; also elsewhere on the board
/H Bridge B/SPX_Q: C20.2, NT4.2, Q4.1 (SOURCE), Q4.2 (SOURCE), Q4.3 (SOURCE), R9.1
/H Bridge B/SXX_N: NT5.1; also elsewhere on the board
/H Bridge B/SXX_P: NT4.1; also elsewhere on the board
/H Bridge C/OUTX: Q5.1 (SOURCE), Q5.2 (SOURCE), Q5.3 (SOURCE), Q6.5 (DRAIN), Q6.6 (DRAIN), Q6.7 (DRAIN), Q6.8 (DRAIN), X3.1; also elsewhere on the board
/H Bridge C/SPX_Q: C21.2, NT6.2, Q6.1 (SOURCE), Q6.2 (SOURCE), Q6.3 (SOURCE), R12.1
/H Bridge C/SXX_N: NT7.1; also elsewhere on the board
/H Bridge C/SXX_P: NT6.1; also elsewhere on the board
GNDPWR: D7.2, D10.2, NT5.2, NT7.2, R9.2, R12.2; also elsewhere on the board
V+: C20.1, C21.1, Q3.5 (DRAIN), Q3.6 (DRAIN), Q3.7 (DRAIN), Q3.8 (DRAIN), Q5.5 (DRAIN), Q5.6 (DRAIN), Q5.7 (DRAIN), Q5.8 (DRAIN); also elsewhere on the board


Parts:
C38, C39, C40, C41, C42, C43, C44, C45, C46, C47, C48, C49: 4.7uF 100V; C_1206_3216Metric; MPN GRJ31CC72A475KE01K

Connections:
GNDPWR: C38.2, C39.2, C40.2, C41.2, C42.2, C43.2, C44.2, C45.2, C46.2, C47.2, C48.2, C49.2; also elsewhere on the board
V+: C38.1, C39.1, C40.1, C41.1, C42.1, C43.1, C44.1, C45.1, C46.1, C47.1, C48.1, C49.1; also elsewhere on the board


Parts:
AUX2: SM07B-GHS-TB(LF)(SN); JST_SM07B-GHS-TB(LF)(SN); MPN SM07B-GHS-TB(LF)(SN)
AUX2H1: Conn_02x04_Odd_Even; PinHeader_2x04_P1.27mm_Vertical
C31, C32: 1uF; C_0402_1005Metric; MPN MF-CAP-0402-1uF
C33, C34, C35, C36: DNP; C_0402_1005Metric; not fitted
D11, D12: BAT41KFILM; SOD-523_STM; MPN BAT41KFILM
R22, R23: 2k; R_0402_1005Metric; MPN MF-RES-0402-2K
R24, R25, R26, R27: 100; R_0402_1005Metric; MPN MF-RES-0402-100

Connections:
+5V: AUX2.1, AUX2H1.2, C31.1; also elsewhere on the board
/aux2/AUX2P_B: AUX2.4, AUX2H1.5, R25.1
/aux2/AUX2P_C: AUX2.5, AUX2H1.3, R26.1
/aux2/AUX2P_D: AUX2.6, AUX2H1.1, R27.1
/aux2/AUX2_A: C36.1, R24.2; also elsewhere on the board
/aux2/AUX2_B: C35.1, R22.2, R25.2; also elsewhere on the board
/aux2/AUX2_C: C34.1, R23.2, R26.2; also elsewhere on the board
/aux2/AUX2_D: C33.1, R27.2; also elsewhere on the board
/aux2/AUX2_I2C_PULLUP: D11.2, D12.2; also elsewhere on the board
unnamed: D11.1, R22.1
unnamed: D12.1, R23.1


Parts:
C23, C24, C25: 1000pF; C_0402_1005Metric; MPN MF-CAP-0402-1nF
R13, R14, R15: 22; R_0402_1005Metric; MPN MF-RES-0402-22

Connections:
/Current Sense/CUR1: R13.1; also elsewhere on the board
/Current Sense/CUR2: R14.1; also elsewhere on the board
/Current Sense/CUR3: R15.1; also elsewhere on the board
/Current Sense/FCUR1: C23.1, R13.2; also elsewhere on the board
/Current Sense/FCUR2: C24.1, R14.2; also elsewhere on the board
/Current Sense/FCUR3: C25.1, R15.2; also elsewhere on the board

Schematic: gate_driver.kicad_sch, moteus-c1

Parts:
C14: 1uF 25V; C_0603_1608Metric; MPN C1608X7R1E105K080AE
C15: 0.1uF 100V; C_0603_1608Metric; MPN GCJ188R72A104KA01D
C16: 47nF 100V; C_0603_1608Metric; MPN C0603X473K1RAC7867
C17: 1uF; C_0402_1005Metric; MPN MF-CAP-0402-1uF
C18: 1uF; C_0603_1608Metric; MPN MF-CAP-0603-1uF
R2, R3: 2k; R_0402_1005Metric; MPN MF-RES-0402-2K
U4: DRV8323SRTAR; RTA0040B; MPN DRV8323SRTAR

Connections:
/Current Sense/CUR1: U4.21 (SOC); also elsewhere on the board
/Current Sense/CUR2: U4.22 (SOB); also elsewhere on the board
/Current Sense/CUR3: U4.23 (SOA); also elsewhere on the board
/Gate Driver/DRV8323_CS: U4.29 (GAIN_SCS_N); also elsewhere on the board
/Gate Driver/DRV8323_FAULT: R3.2, U4.25 (FAULT_N); also elsewhere on the board
/Gate Driver/DRV8323_MOSI: U4.27 (IDRIVE_SDI); also elsewhere on the board
/Gate Driver/DRV8323_SCLK: U4.28 (VDS_SCLK); also elsewhere on the board
/Gate Driver/GHA: U4.6 (GHA); also elsewhere on the board
/Gate Driver/GHB: U4.15 (GHB); also elsewhere on the board
/Gate Driver/GHC: U4.16 (GHC); also elsewhere on the board
/Gate Driver/GLA: U4.8 (GLA); also elsewhere on the board
/Gate Driver/GLB: U4.13 (GLB); also elsewhere on the board
/Gate Driver/GLC: U4.18 (GLC); also elsewhere on the board
/Gate Driver/MOTOR1: U4.34 (INHA); also elsewhere on the board
/Gate Driver/MOTOR2: U4.36 (INHB); also elsewhere on the board
/Gate Driver/MOTOR3: U4.38 (INHC); also elsewhere on the board
/Gate Driver/MOTOR_ENABLE: U4.30 (ENABLE); also elsewhere on the board
/Gate Driver/MOTOR_HIZ: U4.35 (INLA), U4.37 (INLB), U4.39 (INLC); also elsewhere on the board
/H Bridge A/OUTX: U4.7 (SHA); also elsewhere on the board
/H Bridge A/SXX_N: U4.10 (SNA); also elsewhere on the board
/H Bridge A/SXX_P: U4.9 (SPA); also elsewhere on the board
/H Bridge B/OUTX: U4.14 (SHB); also elsewhere on the board
/H Bridge B/SXX_N: U4.11 (SNB); also elsewhere on the board
/H Bridge B/SXX_P: U4.12 (SPB); also elsewhere on the board
/H Bridge C/OUTX: U4.17 (SHC); also elsewhere on the board
/H Bridge C/SXX_N: U4.20 (SNC); also elsewhere on the board
/H Bridge C/SXX_P: U4.19 (SPC); also elsewhere on the board
GNDPWR: C15.1, U4.40 (PGND), U4.41 (PAD); also elsewhere on the board
unnamed: C16.2, U4.2 (CPH)
unnamed: C16.1, U4.1 (CPL)
unnamed: C17.2, U4.33 (DVDD)
unnamed: C14.2, U4.3 (VCP)
V+: C14.1, C15.2, U4.4 (VM), U4.5 (VDRAIN); also elsewhere on the board

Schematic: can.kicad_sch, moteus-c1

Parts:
C26, C27: 0.1uF; C_0402_1005Metric; MPN MF-CAP-0402-0.1uF
CAN1: S3B-PH-SM4-TB(LF)(SN); JST_S3B-PH-SM4-TB(LF)(SN); MPN S3B-PH-SM4-TB(LF)(SN)
CAN_DBG1: Conn_01x03_Pin; PinHeader_1x03_P2.00mm_Vertical
R16: 120; R_0603_1608Metric; MPN RC0805FR-07120RL; not fitted
U5: TCAN1057AEV-Q1; SOIC-8_3.9x4.9mm_P1.27mm; MPN TCAN1057AEVDRQ1

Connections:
+5V: C27.1, U5.3 (VCC); also elsewhere on the board
/CAN/CAN_N: CAN1.2, CAN_DBG1.2, R16.2, U5.6 (CANL)
/CAN/CAN_P: CAN1.1, CAN_DBG1.1, R16.1, U5.7 (CANH)
/CAN/CAN_RX: U5.4 (RXD); also elsewhere on the board
/CAN/CAN_TX: U5.1 (TXD); also elsewhere on the board

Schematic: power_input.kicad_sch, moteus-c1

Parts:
C1: 1uF 100V; C_0805_2012Metric; MPN GCM21BC72A105KE36L
C2: 22uF; C_1206_3216Metric; MPN GRM31CR71A226KE15L
C3, C4: 1uF; C_0402_1005Metric; MPN MF-CAP-0402-1uF
C5: 1uF; C_0603_1608Metric; MPN MF-CAP-0603-1uF
C22: DNP; C_0402_1005Metric; not fitted
D1: SMBJ48D-M3/I; D_SMB; MPN SMBJ48D-M3/I
J1: XT30PW-M; AMASS_XT30PW-M; MPN XT30PW-M
L1: 47uH; IND_4018-WE-LQS_WRE; MPN 74404042470
NT1: NetTie_2; NetTie-2_SMD_Pad0.254mm
R1: 0; R_0402_1005Metric; MPN MF-RES-0402-0
R4: DNP; R_0402_1005Metric; not fitted
U1: MAX15062BATA+T; 21-0487A_MXM; MPN MAX15062BATA+T
U2: TLV70233PDBVR; SOT-23-5; MPN TLV70233PDBVR
VN1: Conn_01x01; POWER_M2.5
VP1: Conn_01x01; POWER_M2.5

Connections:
+5V: C2.1, C3.1, L1.1, U1.4 (FB/VOUT), U2.1 (IN), U2.3 (EN); also elsewhere on the board
GNDPWR: C1.2, C5.2, C22.2, D1.2 (A2), J1.N, NT1.1, R4.2, VN1.1; also elsewhere on the board
MOUNT_GND: C22.1, R4.1; also elsewhere on the board
unnamed: L1.2, U1.8 (LX)
unnamed: R1.1, U1.5 (MODE)
unnamed: C5.1, U1.3 (VCC)
V+: C1.1, D1.1 (A1), J1.P, U1.1 (VIN), U1.2 (EN/UVLO), VP1.1; also elsewhere on the board

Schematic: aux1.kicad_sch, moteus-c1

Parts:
AUX1: Conn_01x04; PinHeader_1x04_P1.27mm_Vertical
C37: 0.1uF; C_0402_1005Metric; MPN MF-CAP-0402-0.1uF
R24: 100; R_0402_1005Metric; MPN MF-RES-0402-100
R28: 0; R_0402_1005Metric; MPN MF-RES-0402-0
U6: AS5047P-ATSM; TSSOP14_OSM; MPN AS5047P-ATSM

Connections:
/aux1/AS5047_CS: U6.1 (CSn); also elsewhere on the board
/aux1/AUX1_A: U6.2 (CLK); also elsewhere on the board
/aux1/AUX1_B: U6.3 (MISO); also elsewhere on the board
/aux1/AUX1_C: U6.4 (MOSI); also elsewhere on the board
/aux2/AUX2_A: R24.2; also elsewhere on the board
unnamed: R28.1, U6.11 (VDD)

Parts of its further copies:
R34, R35: 100; R_0402_1005Metric; MPN MF-RES-0402-100

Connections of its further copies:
/aux1/AUX1_D: R34.2; also elsewhere on the board
/aux1/AUX1_E: R35.2; also elsewhere on the board

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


Board: 4 copper layers, 38.0 x 38.0 mm, 125 parts (64 on the bottom side), 83 nets.

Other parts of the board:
MOUNT1, MOUNT2, MOUNT3, MOUNT4: M2.5_MOUNT
R32: DNP; R_0402_1005Metric
R33: 100k; R_0402_1005Metric

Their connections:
MOUNT_GND: MOUNT3.1; also elsewhere on the board

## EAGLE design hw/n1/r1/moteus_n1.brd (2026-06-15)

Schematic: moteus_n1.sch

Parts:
A: PAD16AWG_TERM; 16AWG_TERM
AUX1: SM08B-GHS-TB(LF)(SN); JST_SM08B-GHS-TB(LF)(SN); MPN SM08B-GHS-TB(LF)(SN)
AUX2: SM07B-GHS-TB(LF)(SN); JST_SM07B-GHS-TB(LF)(SN); MPN SM07B-GHS-TB(LF)(SN)
B: PAD16AWG_TERM; 16AWG_TERM
C: PAD16AWG_TERM; 16AWG_TERM
C1, C18, C19, C20, C21, C24, C25, C26: DNP; C0402
C2: 1uF 100V; C0805; MPN GCM21BC72A105KE36L
C3, C16, C17, C22, C23: 1uF; C0603; MPN MF-CAP-0603-1uF
C4, C13: 10uF; C1206; MPN MF-CAP-1206-10uF
C5, C10, C34, C36, C37: 1uF; C0402; MPN MF-CAP-0402-1uF
C6: 22uF; C1206; MPN CL31B226KPHNNNE
C7, C8, C9, C11, C12, C14, C15, C28, C29, C38: 0.1uF; C0402; MPN MF-CAP-0402-0.1uF
C27: 0.01uF; C0402; MPN MF-CAP-0402-0.01uF
C30, C31, C32: 1000pF; C0402; MPN MF-CAP-0402-1nF
C33, C35: 0.1uF 100V; C0603; MPN GCJ188R72A104KA01D
C39: 0.47uF 100V; C0805; MPN 08051C474KAT2A
C40, C41, C42: 0.1uF 100V; C1206; MPN 12061C104KAT2A
C43, C44: 100uF 63V; EEHZS1V471UP; MANUFACTURER_PART_NUMBER EEH-ZU1J101V
C45, C46, C47: 4.7uF 100V; C1206; MPN GRJ31CC72A475KE01K
C48, C49, C50, C51, C52, C53, C54, C55, C56, C57, C58, C59, C60: 4.7uF 100V; C1206_NOCREAM_NOBORDER; MPN GRJ31CC72A475KE01K
CAN1, CAN2: JST-PH3; JST_S3B-PH-SM4-TB(LF)(SN); MPN S3B-PH-SM4-TB(LF)(SN)
D1: MF-LED-0603-RED; LED0603
D2: MF-LED-0603-RED; LED0603; MPN MF-LED-0603-GREEN
D3, D4, D5, D6, D7, D8, D9, D10, D11: BAT41KFILM; SODFL1608X70N; MPN BAT41KFILM
D12: DIODE-DO214AA; DO214AA; MPN TPSMB51A-VR
D33, D50: PAD24AWG_PAD; 24AWG_PAD
DAC: PAD24AWG_PAD; 24AWG_PAD
DG1: PAD24AWG_PAD; 24AWG_PAD
DTR: PAD24AWG_PAD; 24AWG_PAD
DTX: PAD24AWG_PAD; 24AWG_PAD
J1, J2: XT30XT30PW_MALE; XT30PW_MALE; MPN XT30PW-M
L1: SRN4018-220M; IND_BOURNS_SRN4018; MANUFACTURER_PART_NUMBER 74404042470
L2: 74404024100; IND_4024100_WRE; MPN 74404024100
M1, M2, M3, M4: MOUNT; M2.5MOUNT
MOT1, MOT2, MOT3: PAD24AWG_PAD; 24AWG_PAD
Q1, Q3, Q5: TPH1R204PL_VIAS; SOP_ADVANCE_8_VIAS; MPN TPH2R408QM,L1Q
Q2, Q4, Q6: TPH1R204PLSOP_ADVANCE_8; SOP_ADVANCE_8; MPN TPH2R408QM,L1Q
R1, R2: DNP; R0402
R3, R15: 100k 1%; R0402; MPN RC0402FR-07100KL
R4, R5, R8, R9, R10, R11, R12, R13, R14: 100; R0402; MPN MF-RES-0402-100
R6, R7, R25, R26: 2k; R0402; MPN MF-RES-0402-2K
R16: 4.7k 1%; R0402; MPN RC0402FR-074K7L
R17: 47k NTC; R0402; MPN NCP15WB473F03RC
R18, R19: 10k 1%; R0402; MPN RC0402FR-0710KL
R20, R21: 560; R0402; MPN MF-RES-0402-560
R22, R23, R24: 22; R0402; MPN MF-RES-0402-22
R27, R28, R30, R31, R32: 7.5; R0402; MPN RC0402FR-077R5L
R29: 7.5; R0805; MPN RC0805FR-077R5L
RA: 0.5mOhm 1% 2W; M1206; MPN HCS1206FTL500
RB: 0.5mOhm 1% 2W; M1206; MPN HCS1206FTL500
RC: 0.5mOhm 1% 2W; M1206; MPN HCS1206FTL500
SH1, SH2, SH3: SHORTT5; SHORT_TOP-50
SH4: SHORTMEDIUM; SHORT_TOP-MEDIUM
SWD: JST-ZH6; JST_S6B-ZR-SM4A-TF(LF)(SN); MPN S6B-ZR-SM4A-TF(LF)(SN)
TEMP1, TEMP2: PAD24AWG_PAD; 24AWG_PAD
U1: MAX15062AATA+T; 21-0487A_MXM; MANUFACTURER_PART_NUMBER MAX15062BATA+T
U2: XC9265A331MR-G; SOT95P280X130-5N; MPN XC9265A331MR-G
U3: STM32G474CEU6; QFN50P700X700X60-49N; MPN STM32G474CEU6
U4: TCAN1042HGV; SOIC8; MPN TCAN1057AEVDRQ1‎
U5: AS5147; TSSOP14; MPN AS5047P-ATSM
U6: CAT25080HU4I-GT3UDFN8_2X3_ONS-M; UDFN8_2X3_ONS-M; MPN CAT24C32HU4I-GT3
U7: DRV8353S; WQFN-40; MPN DRV8353FSRTAR
VN: PAD16AWG_TERM; 16AWG_TERM
VP: PAD16AWG_TERM; 16AWG_TERM

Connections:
+3V3: AUX1.2, AUX2.2, C6.P$1, C7.P$1, C8.P$1, C10.P$1, C11.P$1, C12.P$1, C13.P$2, C15.P$1, C17.P$1, C23.P$1, C38.P$2, D33.P$1, L2.1, R2.P$2, R17.P$1, R20.P$1, R21.P$1, R25.P$1, R26.P$1, SWD.6, TEMP1.P$1, U2.4 (VOUT), U3.1 (VBAT), U3.20 (VREF+), U3.21 (VDDA), U3.23 (VDD_1), U3.35 (VDD_2), U3.48 (VDD_3), U4.5 (VIO), U5.12 (VDD3V), U6.3 (!WP), U6.7 (!HOLD), U6.8 (VCC), U7.24 (VREF)
+5V: AUX1.1, AUX2.1, C4.P$1, C5.P$1, C14.P$1, C16.P$1, C22.P$1, D50.P$1, L1.1, U1.4 (FB/VOUT), U2.1 (VIN), U2.3 (CE), U4.3 (VCC)
AS5047_CS: U3.42 (PB4), U5.1 (CS/)
AS5047_MISO: C26.P$1, R12.P$2, U3.40 (PC11), U5.3 (MISO)
AS5047_MOSI: C25.P$1, R13.P$2, U3.43 (PB5), U5.4 (MOSI)
AS5047_SCK: C24.P$1, R14.P$2, U3.39 (PC10), U5.2 (CLK)
AUX_SC1: C20.P$1, R5.P$2, U3.27 (PB14)
AUX_SC2: C21.P$1, R4.P$2, U3.28 (PB15)
AUX_SCL: C19.P$1, R9.P$2, U3.46 (PB8-BOOT0)
AUX_SDA: C18.P$1, R8.P$2, U3.26 (PB13), U3.47 (PB9)
CAN_N: CAN1.2, CAN2.2, U4.6 (CANL)
CAN_P: CAN1.1, CAN2.1, U4.7 (CANH)
CAN_RX: U3.33 (PA11), U4.4 (RXD)
CAN_TX: U3.34 (PA12), U4.1 (TXD)
CUR1: R22.P$1, U7.23 (SOA)
CUR2: R23.P$1, U7.22 (SOB)
CUR3: R24.P$1, U7.21 (SOC)
DAC: DAC.P$1, R2.P$1, R3.P$2, U3.12 (PA4)
DEBUG_RX: DTR.P$1, U3.45 (PB7)
DEBUG_TX: DTX.P$1, U3.44 (PB6)
DRV8323_CS: U3.17 (PB0), U7.30 (CS)
DRV8323_MISO: R25.P$2, U3.14 (PA6), U6.2 (SO), U7.27 (MISO)
DRV8323_MOSI: U3.15 (PA7), U6.5 (SI), U7.28 (MOSI)
DRV8323_SCLK: U3.13 (PA5), U6.6 (SCK), U7.29 (SCLK)
EEPROM_CS: U3.38 (PA15), U6.1 (!CS)
FCUR1: C30.P$1, R22.P$2, U3.11 (PA3)
FCUR2: C31.P$1, R23.P$2, U3.16 (PC4)
FCUR3: C32.P$1, R24.P$2, U3.18 (PB1)
GHA: D5.1 (K), R28.P$1, U7.6 (GHA)
GHA_D: D5.2 (A), Q1.4 (G), R28.P$2
GHB: D8.1 (K), R30.P$1, U7.15 (GHB)
GHB_D: D8.2 (A), Q3.4 (G), R30.P$2
GHC: D11.1 (K), R32.P$1, U7.16 (GHC)
GHC_D: D11.2 (A), Q5.4 (G), R32.P$2
GLA: D3.1 (K), R27.P$1, U7.8 (GLA)
GLA_D: D3.2 (A), D4.1 (K), Q2.4 (G), R27.P$2
GLB: D6.1 (K), R29.P$1, U7.13 (GLB)
GLB_D: D6.2 (A), D7.1 (K), Q4.4 (G), R29.P$2
GLC: D9.1 (K), R31.P$1, U7.18 (GLC)
GLC_D: D9.2 (A), D10.1 (K), Q6.4 (G), R31.P$2
GND: AUX1.8, AUX2.7, C3.P$2, C4.P$2, C5.P$2, C6.P$2, C7.P$2, C8.P$2, C9.P$2, C10.P$2, C11.P$2, C12.P$2, C13.P$1, C14.P$2, C15.P$2, C16.P$2, C17.P$2, C18.P$2, C19.P$2, C20.P$2, C21.P$2, C22.P$2, C23.P$2, C24.P$2, C25.P$2, C26.P$2, C27.P$2, C28.P$2, C29.P$2, C30.P$2, C31.P$2, C32.P$2, C38.P$1, CAN1.3, CAN2.3, DG1.P$1, R3.P$1, R16.P$1, R18.P$2, R19.P$2, SH4.2, SWD.4, U1.7 (GND), U2.2 (GND), U3.49 (THERMALPAD), U4.2 (GND), U4.8 (STB), U5.5 (TEST), U5.13 (GND), U6.4 (VSS), U7.25 (AGND)
I2C_PULLUP: R6.P$1, R7.P$1, U3.41 (PB3)
LED1: D1.CATHODE, U3.5 (PF0-OSC_IN)
LED2: D2.CATHODE, U3.6 (PF1-OSC_OUT)
MOTOR1: MOT1.P$1, U3.8 (PA0), U7.32 (INHA)
MOTOR2: MOT2.P$1, U3.9 (PA1), U7.34 (INHB)
MOTOR3: MOT3.P$1, U3.10 (PA2), U7.36 (INHC)
MOTOR_ENABLE: U3.3 (PC14-OSC32_IN), U7.31 (ENABLE)
MOTOR_FAULT: R26.P$2, U3.2 (PC13), U7.26 (FAULT)
MOTOR_HIZ: U3.4 (PC15-OSC32_OUT), U7.33 (INLA), U7.35 (INLB), U7.37 (INLC)
unnamed: C1.P$1, M3.P$1, R1.P$1
unnamed: C36.P$2, U7.40 (VGLS)
unnamed: AUX2.3, R4.P$1
unnamed: C3.P$1, U1.3 (VCC)
unnamed: L2.2, U2.5 (LX)
unnamed: AUX2.4, R5.P$1
unnamed: AUX2.6, R6.P$2, R8.P$1
unnamed: AUX2.5, R7.P$2, R9.P$1
unnamed: AUX1.3, R10.P$1
unnamed: C35.P$2, U7.1 (CPL)
unnamed: AUX1.4, R11.P$1
unnamed: AUX1.5, R12.P$1
unnamed: C35.P$1, U7.2 (CPH)
unnamed: C34.P$2, U7.5 (VCP)
unnamed: AUX1.6, R13.P$1
unnamed: C37.P$2, U7.38 (DVDD)
unnamed: D1.ANODE, R20.P$2
unnamed: D2.ANODE, R21.P$2
unnamed: AUX1.7, R14.P$1
NRST: C9.P$1, SWD.2, U3.7 (PG10-NRST)
PRIMARY_CS: R11.P$2, U3.19 (PB2)
PRIMARY_EXTRA: R10.P$2, U3.24 (PB11)
S1: AUX2.S1
S2: AUX2.S2
SHA: A.1, A.2, A.3, A.4, A.5, A.6, A.7, A.8, A.9, A.10, A.11, A.12, Q1.1 (S), Q1.2 (S), Q1.3 (S), Q2.5 (D), Q2.6 (D), Q2.7 (D), Q2.8 (D), Q2.PAD (D), U7.7 (SHA)
SHB: B.1, B.2, B.3, B.4, B.5, B.6, B.7, B.8, B.9, B.10, B.11, B.12, Q3.1 (S), Q3.2 (S), Q3.3 (S), Q4.5 (D), Q4.6 (D), Q4.7 (D), Q4.8 (D), Q4.PAD (D), U7.14 (SHB)
SHC: C.1, C.2, C.3, C.4, C.5, C.6, C.7, C.8, C.9, C.10, C.11, C.12, Q5.1 (S), Q5.2 (S), Q5.3 (S), Q6.5 (D), Q6.6 (D), Q6.7 (D), Q6.8 (D), Q6.PAD (D), U7.17 (SHC)
SWCLK: SWD.5, U3.37 (PA14)
SWDIO: SWD.3, U3.36 (PA13)
SXA_N: SH1.1, U7.10 (SNA)
SXA_P: C40.P$2, Q2.1 (S), Q2.2 (S), Q2.3 (S), RA.2, U7.9 (SPA)
SXB_N: SH2.1, U7.11 (SNB)
SXB_P: C41.P$2, Q4.1 (S), Q4.2 (S), Q4.3 (S), RB.2, U7.12 (SPB)
SXC_N: SH3.1, U7.20 (SNC)
SXC_P: C42.P$2, Q6.1 (S), Q6.2 (S), Q6.3 (S), RC.2, U7.19 (SPC)
V+: C2.P$1, C33.P$1, C34.P$1, C39.P$1, C40.P$1, C41.P$1, C42.P$1, C43.1 (+), C44.1 (+), C45.P$1, C46.P$1, C47.P$1, C48.P$1, C49.P$1, C50.P$1, C51.P$1, C52.P$1, C53.P$1, C54.P$1, C55.P$1, C56.P$1, C57.P$1, C58.P$1, C59.P$1, C60.P$1, D12.C, J1.1, J2.1, Q1.5 (D), Q1.6 (D), Q1.7 (D), Q1.8 (D), Q1.PAD (D), Q3.5 (D), Q3.6 (D), Q3.7 (D), Q3.8 (D), Q3.PAD (D), Q5.5 (D), Q5.6 (D), Q5.7 (D), Q5.8 (D), Q5.PAD (D), R15.P$2, U1.1 (VIN), U1.2 (EN/UVLO), U7.3 (VM), U7.4 (VDRAIN), VP.1, VP.2, VP.3, VP.4, VP.5, VP.6, VP.7, VP.8, VP.9, VP.10, VP.11, VP.12
V-: C1.P$2, C2.P$2, C33.P$2, C36.P$1, C37.P$1, C39.P$2, C43.2 (-), C44.2 (-), C45.P$2, C46.P$2, C47.P$2, C48.P$2, C49.P$2, C50.P$2, C51.P$2, C52.P$2, C53.P$2, C54.P$2, C55.P$2, C56.P$2, C57.P$2, C58.P$2, C59.P$2, C60.P$2, D4.2 (A), D7.2 (A), D10.2 (A), D12.A, J1.2, J2.2, R1.P$2, RA.1, RB.1, RC.1, SH1.2, SH2.2, SH3.2, SH4.1, U7.39 (GND), U7.P1 (PAD), U7.P2 (PAD), U7.P3 (PAD), U7.P7 (PAD), U7.P8 (PAD), U7.P9 (PAD), U7.P12 (PAD), U7.P13 (PAD), U7.P14 (PAD), U7.P17 (PAD), U7.P18 (PAD), U7.P19 (PAD), U7.PAD, VN.1, VN.2, VN.3, VN.4, VN.5, VN.6, VN.7, VN.8, VN.9, VN.10, VN.11, VN.12
VBAT_SENSE: C27.P$1, R15.P$1, R16.P$2, U3.31 (PA9)
VSW: L1.2, U1.8 (LX)
VTEMP_FET: C28.P$1, R17.P$2, R18.P$1, U3.25 (PB12)
VTEMP_MOT: C29.P$1, R19.P$1, TEMP2.P$1, U3.30 (PA8)

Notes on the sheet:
PCB rev divider HI / LO r1 - open / 100k



Board: 4 copper layers, 46.0 x 46.0 mm, 153 parts (82 on the bottom side), 89 nets.

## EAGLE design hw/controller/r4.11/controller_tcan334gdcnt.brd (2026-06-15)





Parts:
A: PAD16AWG_PAD; 16AWG_PAD
ABS: JST_ZH4; JST_S4B-ZR-SM4A-TF(LF)(SN); MPN S4B-ZR-SM4A-TF(LF)(SN)
B: PAD16AWG_PAD; 16AWG_PAD
C: PAD16AWG_PAD; 16AWG_PAD
C1, C2, C3, C5, C6, C8, C10, C12, C13, C18: 0.1uF; C0402; MPN MF-CAP-0402-0.1uF
C4, C9, C15, C17, C56: 1uF; C0402; MPN MF-CAP-0402-1uF
C7, C21: 10uF; C1206; MPN MF-CAP-1206-10uF
C11: 0.1uF; C0402_NOBORDER; MPN MF-CAP-0402-0.1uF
C14, C16: 0.1uF 50V; C0402; MPN CGA2B3X7R1H104K050BB
C19: 0.47uF 50V; C0402; MPN GRM155R61H474KE11D
C20: 1uF; C0603; MPN MF-CAP-0603-1uF
C22, C23, C24, C25, C26, C27, C28, C29, C30, C31, C32, C33, C34, C36, C37: 10uF 50V; C1206; MPN C3216X7R1H106K160AE
C35: 10uF 50V; C1206_NOBORDER; MPN C3216X7R1H106K160AE
C38: 1uF; C0603; MPN C1608X7R1E105K080AE
C39: 1uF 100V; C0805; MPN GCM21BC72A105KE36L
C40, C41, C42, C43, C44, C45, C46, C47, C48, C49, C50, C51, C52, C53, C54: DNP; C1206_NOCREAM
C55: DNP; C0402
C57: 0.01uF; C0402; MPN MF-CAP-0402-0.01uF
C58, C59, C60: 1000pF; C0402_NOBORDER; MPN MF-CAP-0402-1nF
C61, C63: 0.1uF 50V; C1206; MPN 12065C104KAZ2A
C62: 0.1uF 50V; C0603_NOBORDER; MPN 06035C104KAZ2A
CAN1, CAN2: JST-PH3; JST_S3B-PH-SM4-TB(LF)(SN); MPN S3B-PH-SM4-TB(LF)(SN)
D1, D5, D6, D7, D8, D9, D10, D11, D12: BAT41KFILM; SODFL1608X70N; MPN BAT41KFILM
D2: MF-LED-0603-RED; LED0603; MPN MF-LED-0603-GREEN
D3: MF-LED-0603-RED; LED0603
D4: DUAL_TVS; SOT23-3; MPN CDSOT23-0502B
D33: PAD24AWG_PAD; 24AWG_PAD
DA: PAD24AWG_PAD; 24AWG_PAD
DAC: PAD24AWG_PAD; 24AWG_PAD
DB: PAD24AWG_PAD; 24AWG_PAD
DBG1, DBG2: PAD24AWG_PAD; 24AWG_PAD
DC: PAD24AWG_PAD; 24AWG_PAD
DG1, DG2: PAD24AWG_PAD; 24AWG_PAD
DRV_CS: PAD24AWG_PAD; 24AWG_PAD
DRV_MISO: PAD24AWG_PAD; 24AWG_PAD
DRV_MOSI: PAD24AWG_PAD; 24AWG_PAD
DRV_SCK: PAD24AWG_PAD; 24AWG_PAD
DTR: PAD24AWG_PAD; 24AWG_PAD
DTX: PAD24AWG_PAD; 24AWG_PAD
ENC: PICO-SPOX-6NOPASTE; PICO-SPOX-SMT-RA-6-NOPASTE
J1, J2: XT30XT30PW_MALE; XT30PW_MALE
L1: SRN4018-220M; IND_BOURNS_SRN4018; MANUFACTURER_PART_NUMBER SRN4018-330M
L2, L3: HALF_CHOKE; 1812_COMMON_HALF; MPN MF-RES-0805-0
M1, M2, M3, M4: MOUNT; M2.5MOUNT
MOT1, MOT2, MOT3: PAD24AWG_PAD; 24AWG_PAD
Q1, Q2, Q3, Q4, Q5, Q6: TPH1R204PLSOP_ADVANCE_8; SOP_ADVANCE_8; MPN TPH2R506PL,L1Q
R1, R2: 560; R0402; MPN MF-RES-0402-560
R3, R4, R13, R14: 2k; R0402; MPN MF-RES-0402-2K
R5: 100k 1%; R0402; MPN RC0402FR-07100KL
R6: 4.7k 1%; R0402; MPN RC0402FR-074K7L
R7, R9: 10k 1%; R0402; MPN RC0402FR-0710KL
R8: 47k NTC; R0402; MPN NCP15WB473F03RC
R10: DNP; R0402
R15, R16, R17: 22; R0402_NOBORDER; MPN MF-RES-0402-22
R22, R23, R24, R25, R26, R27: 7.5; R0402; MPN RC0402FR-077R5L
RA: 0.5mOhm 1% 2W; M1206; MPN HCS1206FTL500
RB: 0.5mOhm 1% 2W; M1206; MPN HCS1206FTL500
RC: 0.5mOhm 1% 2W; M1206; MPN HCS1206FTL500
SH1, SH2, SH3: SHORTT5; SHORT_TOP-50
SH4: SHORTMEDIUM; SHORT_TOP-MEDIUM
SWD: JST-ZH6; JST_S6B-ZR-SM4A-TF(LF)(SN); MPN S6B-ZR-SM4A-TF(LF)(SN)
TEMP1, TEMP2: PAD24AWG_PAD; 24AWG_PAD
U1: STM32G474CEU6; QFN50P700X700X60-49N; MPN STM32G474CEU6
U2: TCAN334G; SOIC8; MPN TCAN337GDR
U3: AS5147; TSSOP14; MPN AS5047P-ATSM
U4: MAX15062AATA+T; 21-0487A_MXM; MPN MAX15062AATA+T
U5: DRV8353S; WQFN-40; MPN DRV8353FSRTAR
U6: TCAN334GSOT23; SOT23-8; MPN TCAN334GDCNT

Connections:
+3V3: ABS.1, C1.P$1, C2.P$1, C4.P$1, C5.P$1, C6.P$1, C7.P$2, C8.P$1, C9.P$1, C10.P$1, C11.P$1, C12.P$1, C18.P$2, C21.P$1, C56.P$1, D33.P$1, ENC.1, L1.1, R1.P$1, R2.P$1, R3.P$1, R4.P$1, R8.P$1, R13.P$1, R14.P$1, SWD.6, TEMP1.P$1, U1.1 (VBAT), U1.20 (VREF+), U1.21 (VDDA), U1.23 (VDD_1), U1.35 (VDD_2), U1.48 (VDD_3), U2.3 (VCC), U3.12 (VDD3V), U4.4 (FB/VOUT), U5.24 (VREF), U6.3 (VCC)
AS5047_A: U1.43 (PB5), U3.7 (A)
AS5047_B: U1.42 (PB4), U3.6 (B)
AS5047_CS: U1.24 (PB11), U3.1 (CS/)
AS5047_MISO: ENC.5, U1.27 (PB14), U3.3 (MISO)
AS5047_MOSI: ENC.6, U1.28 (PB15), U3.4 (MOSI)
AS5047_SCK: ENC.4, U1.26 (PB13), U3.2 (CLK)
CAN2_N: L2.P$2 (2), U2.6 (CANL), U6.6 (CANL)
CAN2_P: L3.P$2 (2), U2.7 (CANH), U6.7 (CANH)
CAN_N: CAN1.2, CAN2.2, D4.2, L2.P$1 (1)
CAN_P: CAN1.1, CAN2.1, D4.1, L3.P$1 (1)
CAN_RX: U1.33 (PA11), U2.4 (RXD), U6.4 (RXD)
CAN_TX: U1.34 (PA12), U2.1 (TXD), U6.1 (TXD)
CUR1: R15.P$1, U5.23 (SOA)
CUR2: R16.P$1, U5.22 (SOB)
CUR3: R17.P$1, U5.21 (SOC)
DAC: DAC.P$1, U1.12 (PA4)
DEBUG1: DBG1.P$1, U1.3 (PC14-OSC32_IN)
DEBUG2: DBG2.P$1, U1.4 (PC15-OSC32_OUT)
DEBUG_RX: DTR.P$1, U1.40 (PC11)
DEBUG_TX: DTX.P$1, U1.39 (PC10)
DRV8323_CS: DRV_CS.P$1, U1.16 (PC4), U5.30 (CS)
DRV8323_MISO: DRV_MISO.P$1, R13.P$2, U1.14 (PA6), U5.27 (MISO)
DRV8323_MOSI: DRV_MOSI.P$1, U1.15 (PA7), U5.28 (MOSI)
DRV8323_SCLK: DRV_SCK.P$1, U1.13 (PA5), U5.29 (SCLK)
FCUR1: C58.P$1, R15.P$2, U1.17 (PB0)
FCUR2: C59.P$1, R16.P$2, U1.18 (PB1)
FCUR3: C60.P$1, R17.P$2, U1.19 (PB2)
GHA: D10.1 (K), R22.P$1, U5.6 (GHA)
GHA_D: D10.2 (A), Q1.4 (G), R22.P$2
GHB: D11.1 (K), R24.P$1, U5.15 (GHB)
GHB_D: D11.2 (A), Q3.4 (G), R24.P$2
GHC: D12.1 (K), R26.P$1, U5.16 (GHC)
GHC_D: D12.2 (A), Q5.4 (G), R26.P$2
GLA: D7.1 (K), R23.P$1, U5.8 (GLA)
GLA_D: D1.1 (K), D7.2 (A), Q2.4 (G), R23.P$2
GLB: D8.1 (K), R25.P$1, U5.13 (GLB)
GLB_D: D5.1 (K), D8.2 (A), Q4.4 (G), R25.P$2
GLC: D9.1 (K), R27.P$1, U5.18 (GLC)
GLC_D: D6.1 (K), D9.2 (A), Q6.4 (G), R27.P$2
GND: ABS.4, C1.P$2, C2.P$2, C3.P$2, C4.P$2, C5.P$2, C6.P$2, C7.P$1, C8.P$2, C9.P$2, C10.P$2, C11.P$2, C12.P$2, C13.P$2, C18.P$1, C20.P$2, C21.P$2, C56.P$2, C57.P$2, C58.P$2, C59.P$2, C60.P$2, CAN1.3, CAN2.3, D4.3, DG1.P$1, DG2.P$1, ENC.3, R6.P$1, R7.P$2, R9.P$2, SH4.2, SWD.4, U1.32 (PA10), U1.49 (THERMALPAD), U2.2 (GND), U2.5 (SHDN), U2.8 (STB), U3.5 (TEST), U3.13 (GND), U4.7 (GND), U5.25 (AGND), U6.2 (GND), U6.5 (SHDN), U6.8 (STB)
I2C_ABS_SCL: ABS.2, R4.P$2, U1.46 (PB8-BOOT0)
I2C_ABS_SDA: ABS.3, R3.P$2, U1.47 (PB9)
LED1: D3.CATHODE, U1.5 (PF0-OSC_IN)
LED2: D2.CATHODE, U1.6 (PF1-OSC_OUT)
MOTOR1: MOT1.P$1, U1.8 (PA0), U5.32 (INHA)
MOTOR2: MOT2.P$1, U1.9 (PA1), U5.34 (INHB)
MOTOR3: MOT3.P$1, U1.10 (PA2), U5.36 (INHC)
MOTOR_ENABLE: U1.11 (PA3), U5.31 (ENABLE)
MOTOR_FAULT: R14.P$2, U1.44 (PB6), U5.26 (FAULT)
MOTOR_HIZ: U1.45 (PB7), U5.33 (INLA), U5.35 (INLB), U5.37 (INLC)
unnamed: C55.P$1, M3.P$1, R10.P$1
unnamed: C38.P$2, U5.40 (VGLS)
unnamed: C20.P$1, U4.3 (VCC)
unnamed: C16.P$2, U5.1 (CPL)
unnamed: C16.P$1, U5.2 (CPH)
unnamed: C15.P$2, U5.5 (VCP)
unnamed: C17.P$2, U5.38 (DVDD)
unnamed: D3.ANODE, R1.P$2
unnamed: D2.ANODE, R2.P$2
NRST: C3.P$1, SWD.2, U1.7 (PG10-NRST)
SECONDARY_ENC_CS: ENC.2, U1.2 (PC13)
SHA: A.1, DA.P$1, Q1.1 (S), Q1.2 (S), Q1.3 (S), Q2.5 (D), Q2.6 (D), Q2.7 (D), Q2.8 (D), Q2.PAD (D), U5.7 (SHA)
SHB: B.1, DB.P$1, Q3.1 (S), Q3.2 (S), Q3.3 (S), Q4.5 (D), Q4.6 (D), Q4.7 (D), Q4.8 (D), Q4.PAD (D), U5.14 (SHB)
SHC: C.1, DC.P$1, Q5.1 (S), Q5.2 (S), Q5.3 (S), Q6.5 (D), Q6.6 (D), Q6.7 (D), Q6.8 (D), Q6.PAD (D), U5.17 (SHC)
SWCLK: SWD.5, U1.37 (PA14)
SWDIO: SWD.3, U1.36 (PA13)
SXA_N: SH1.1, U5.10 (SNA)
SXA_P: C61.P$2, Q2.1 (S), Q2.2 (S), Q2.3 (S), RA.2, U5.9 (SPA)
SXB_N: SH2.1, U5.11 (SNB)
SXB_P: C62.P$2, Q4.1 (S), Q4.2 (S), Q4.3 (S), RB.2, U5.12 (SPB)
SXC_N: SH3.1, U5.20 (SNC)
SXC_P: C63.P$2, Q6.1 (S), Q6.2 (S), Q6.3 (S), RC.2, U5.19 (SPC)
V+: C14.P$1, C15.P$1, C19.P$1, C22.P$1, C23.P$1, C24.P$1, C25.P$1, C26.P$1, C27.P$1, C28.P$1, C29.P$1, C30.P$1, C31.P$1, C32.P$1, C33.P$1, C34.P$1, C35.P$1, C36.P$1, C37.P$1, C39.P$1, C40.P$1, C41.P$1, C42.P$1, C43.P$1, C44.P$1, C45.P$1, C46.P$1, C47.P$1, C48.P$1, C49.P$1, C50.P$1, C51.P$1, C52.P$1, C53.P$1, C54.P$1, C61.P$1, C62.P$1, C63.P$1, J1.1, J2.1, Q1.5 (D), Q1.6 (D), Q1.7 (D), Q1.8 (D), Q1.PAD (D), Q3.5 (D), Q3.6 (D), Q3.7 (D), Q3.8 (D), Q3.PAD (D), Q5.5 (D), Q5.6 (D), Q5.7 (D), Q5.8 (D), Q5.PAD (D), R5.P$2, U4.1 (VIN), U4.2 (EN/UVLO), U5.3 (VM), U5.4 (VDRAIN)
V-: C14.P$2, C17.P$1, C19.P$2, C22.P$2, C23.P$2, C24.P$2, C25.P$2, C26.P$2, C27.P$2, C28.P$2, C29.P$2, C30.P$2, C31.P$2, C32.P$2, C33.P$2, C34.P$2, C35.P$2, C36.P$2, C37.P$2, C38.P$1, C39.P$2, C40.P$2, C41.P$2, C42.P$2, C43.P$2, C44.P$2, C45.P$2, C46.P$2, C47.P$2, C48.P$2, C49.P$2, C50.P$2, C51.P$2, C52.P$2, C53.P$2, C54.P$2, C55.P$2, D1.2 (A), D5.2 (A), D6.2 (A), J1.2, J2.2, R10.P$2, RA.1, RB.1, RC.1, SH1.2, SH2.2, SH3.2, SH4.1, U5.39 (GND), U5.P1 (PAD), U5.P2 (PAD), U5.P3 (PAD), U5.P7 (PAD), U5.P8 (PAD), U5.P9 (PAD), U5.P12 (PAD), U5.P13 (PAD), U5.P14 (PAD), U5.P17 (PAD), U5.P18 (PAD), U5.P19 (PAD), U5.PAD
VBAT_SENSE: C57.P$1, R5.P$1, R6.P$2, U1.25 (PB12)
VSW: L1.2, U4.8 (LX)
VTEMP_FET: C13.P$1, R8.P$2, R9.P$1, U1.31 (PA9)
VTEMP_MOT: R7.P$1, TEMP2.P$1, U1.30 (PA8)

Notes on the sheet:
PA10/PA15/PC6 Version 011
L2/L3 SIZED TO HOLD EITHER A) 2x 0805 0 OHM RESISTORS B) A COILCRAFT 1812CAN SERIES COMMON MODE CHOKE
ALTERNATE PARTS CAN USE SOIC-8 OR SOT-23 FOOTPRINTS



Board: 4 copper layers, 46.0 x 53.0 mm, 152 parts (23 on the bottom side), 79 nets.

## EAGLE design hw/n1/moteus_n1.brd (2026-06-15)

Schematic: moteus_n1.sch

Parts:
A: PAD16AWG_TERM; 16AWG_TERM
AUX1: SM08B-GHS-TB(LF)(SN); JST_SM08B-GHS-TB(LF)(SN); MPN SM08B-GHS-TB(LF)(SN)
AUX2: SM07B-GHS-TB(LF)(SN); JST_SM07B-GHS-TB(LF)(SN); MPN SM07B-GHS-TB(LF)(SN)
AUX2H: PH2X4
B: PAD16AWG_TERM; 16AWG_TERM
C: PAD16AWG_TERM; 16AWG_TERM
C1, C19, C20, C21, C22, C25, C26, C27, C28, C29: DNP; C0402
C2: 1uF 100V; C0805; MPN GCM21BC72A105KE36L
C3, C17, C18, C23\, C24: 1uF; C0603; MPN MF-CAP-0603-1uF
C4: 22uF; C1206; MPN GRM31CR71A226KE15L
C5, C11, C23, C41: 1uF; C0402; MPN MF-CAP-0402-1uF
C6: 22uF; C1206; MPN CL31B226KPHNNNE
C7, C8, C9, C12, C14, C15, C16, C30, C32, C33, C42, C87: 0.1uF; C0402; MPN MF-CAP-0402-0.1uF
C10: 4.7uF; C0603; MPN CL10A475KP8NNNC
C13: 10uF; C1206; MPN MF-CAP-1206-10uF
C31: 0.01uF; C0402; MPN MF-CAP-0402-0.01uF
C34, C35, C36: 1000pF; C0402; MPN MF-CAP-0402-1nF
C37, C39: 0.1uF 100V; C0603; MPN GCJ188R72A104KA01D
C38, C40: 1uF; C0603; MPN C1608X7R1E105K080AE
C43: 0.47uF 100V; C0805; MPN 08051C474KAT2A
C44, C45, C46: 0.1uF 100V; C1206; MPN 12061C104KAT2A
C47, C48: 4.7uF 100V; C1206; MPN GRJ31CC72A475KE01K
C49, C50, C51, C52, C53, C54, C55, C56, C57, C58, C59, C60, C61, C62, C63, C64, C65, C66, C67, C68, C69, C70, C71, C72, C73, C74, C75, C76, C77, C78, C79, C80, C81, C82, C83, C84, C85, C86: 4.7uF 100V; C1206_NOBORDER; MPN GRJ31CC72A475KE01K
CAN1, CAN2: JST-PH3; JST_S3B-PH-SM4-TB(LF)(SN); MPN S3B-PH-SM4-TB(LF)(SN)
CAN_DBG: 1X3
D1: MF-LED-0603-RED; LED0603
D2: MF-LED-0603-RED; LED0603; MPN MF-LED-0603-GREEN
D3, D4, D5, D6, D7, D8, D9, D10, D11, D13, D14, D15, D16: BAT41KFILM; SODFL1608X70N; MPN BAT41KFILM
D12: DIODE-DO214AA; DO214AA; MPN SMBJ51D-M3/I
D33, D50: PAD24AWG_PAD; 24AWG_PAD
DAC: PAD24AWG_PAD; 24AWG_PAD
DG1: PAD24AWG_PAD; 24AWG_PAD
DTR: PAD24AWG_PAD; 24AWG_PAD
DTX: PAD24AWG_PAD; 24AWG_PAD
J1, J2: XT30XT30PW_MALE; XT30PW_MALE; MPN XT30PW-M
J3: SM06B-GHS-TB(LF)(SN); JST_SM06B-GHS-TB(LF)(SN); MPN SM06B-GHS-TB(LF)(SN)
L1: SRN4018-220M; IND_BOURNS_SRN4018; MANUFACTURER_PART_NUMBER 74404042470
L2: 74479887222A; IND_1008_WE-PMI_WRE; MPN 74479887222A
M1, M2, M3, M4: MOUNT; M2.5MOUNT
Q1, Q3, Q5: TPH1R204PL_VIAS; SOP_ADVANCE_8_VIAS; MPN TPH2R408QM,L1Q
Q2, Q4, Q6: TPH1R204PLSOP_ADVANCE_8; SOP_ADVANCE_8; MPN TPH2R408QM,L1Q
R1, R3: DNP; R0402
R2, R15: 100k 1%; R0402; MPN RC0402FR-07100KL
R4, R5, R8, R9, R10, R11, R12, R13, R14: 100; R0402; MPN MF-RES-0402-100
R6, R7, R25, R26, R33, R34: 2k; R0402; MPN MF-RES-0402-2K
R16: 4.7k 1%; R0402; MPN RC0402FR-074K7L
R17: 47k NTC; R0402; MPN NCP15WB473F03RC
R18, R19: 10k 1%; R0402; MPN RC0402FR-0710KL
R20, R21: 560; R0402; MPN MF-RES-0402-560
R22, R23, R24: 22; R0402; MPN MF-RES-0402-22
R27, R28, R30, R31, R32: 7.5; R0402; MPN RC0402FR-077R5L
R29: 7.5; R0805; MPN RC0805FR-077R5L
R35, R36: 120; R0402; MPN RC0402FR-07120RL
R37: DNP; R0805
R38, R39, R40: 0; R0402; MPN MF-RES-0402-0
RA: 0.5mOhm 1% 2W; M1206; MPN HCS1206FTL500
RB: 0.5mOhm 1% 2W; M1206; MPN HCS1206FTL500
RC: 0.5mOhm 1% 2W; M1206; MPN HCS1206FTL500
SH1, SH2, SH3: SHORTT5; SHORT_TOP-50
SH4: SHORTMEDIUM; SHORT_TOP-MEDIUM
SWD: JST-ZH6; JST_S6B-ZR-SM4A-TF(LF)(SN); MPN S6B-ZR-SM4A-TF(LF)(SN)
TEMP: 1X2
U1: MAX15062BATA+T; 21-0487A_MXM; MANUFACTURER_PART_NUMBER MAX15062BATA+T
U2: ADP5301ACBZ-4-R7; BGA9C50P3X3_165X187X66; MPN ADP5301ACBZ-4-R7
U3: STM32G474CEU6; QFN50P700X700X60-49N; MPN STM32G474CEU6
U4: TCAN1042HGV; SOIC8; MPN TCAN1057AEVDRQ1
U5: AS5147; TSSOP14; MPN AS5047P-ATSM
U7: DRV8353S; WQFN-40; MPN DRV8353FSRTAR
U8: SN65HVD35DR; D14
VN: PAD16AWG_TERM; 16AWG_TERM
VP: PAD16AWG_TERM; 16AWG_TERM

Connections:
+3V3: AUX1.2, AUX2.2, AUX2H.P$4 (4), C6.P$1, C7.P$1, C8.P$1, C10.P$1, C11.P$1, C12.P$1, C13.P$2, C15.P$1, C16.P$1, C18.P$1, C23.P$1, C24.P$1, C30.P$1, C42.P$2, C87.P$1, D33.P$1, L2.1, R2.P$2, R17.P$1, R20.P$1, R21.P$1, R25.P$1, R26.P$1, R40.P$2, SWD.6, TEMP.1, U2.C2 (FB), U3.1 (VBAT), U3.20 (VREF+), U3.21 (VDDA), U3.23 (VDD_1), U3.35 (VDD_2), U3.48 (VDD_3), U4.5 (VIO), U5.12 (VDD3V), U7.24 (VREF), U8.13 (VCC_2), U8.14 (VCC)
+5V: AUX1.1, AUX2.1, AUX2H.P$2 (2), C4.P$1, C5.P$1, C14.P$1, C17.P$1, C23\.P$1, D50.P$1, J3.1, L1.1, R39.P$2, U1.4 (FB/VOUT), U2.A2 (PVIN), U2.A3 (EN), U4.3 (VCC)
AS5047_CS: U3.19 (PB2), U5.1 (CS/)
AUX1P_A: AUX1.3, R10.P$1
AUX1P_B: AUX1.4, R11.P$1
AUX1P_C: AUX1.5, R12.P$1
AUX1P_D: AUX1.6, R13.P$1
AUX1P_E: AUX1.7, R14.P$1
AUX1_A: C29.P$1, R10.P$2, U3.13 (PA5), U3.27 (PB14), U5.2 (CLK)
AUX1_B: C28.P$1, R11.P$2, U3.42 (PB4), U5.3 (MISO)
AUX1_C: C27.P$1, R12.P$2, U3.15 (PA7), U5.4 (MOSI)
AUX1_D: C26.P$1, DTR.P$1, R13.P$2, R34.P$2, U3.38 (PA15), U8.2 (R)
AUX1_E: C25.P$1, DTX.P$1, R14.P$2, R33.P$2, U3.41 (PB3), U3.47 (PB9), U8.5 (D)
AUX1_I2C_PULLUP: D13.2 (A), D14.2 (A), U3.46 (PB8-BOOT0)
AUX2P_A: AUX2.3, AUX2H.P$7 (7), AUX2H.P$8 (8), R4.P$1
AUX2P_B: AUX2.4, AUX2H.P$5 (5), R5.P$1
AUX2P_C: AUX2.5, AUX2H.P$3 (3), R9.P$1
AUX2P_D: AUX2.6, AUX2H.P$1 (1), R8.P$1
AUX2_A: C22.P$1, R4.P$2, U3.6 (PF1-OSC_OUT)
AUX2_B: C21.P$1, R5.P$2, R6.P$2, U3.5 (PF0-OSC_IN), U3.32 (PA10)
AUX2_C: C20.P$1, R7.P$2, R9.P$2, U3.16 (PC4), U3.33 (PA11)
AUX2_D: C19.P$1, R8.P$2, U3.45 (PB7)
AUX2_I2C_PULLUP: D15.2 (A), D16.2 (A), U3.34 (PA12)
CAN_N: CAN1.2, CAN2.2, CAN_DBG.2, R37.P$2, U4.6 (CANL)
CAN_P: CAN1.1, CAN2.1, CAN_DBG.1, R37.P$1, U4.7 (CANH)
CAN_RX: U3.43 (PB5), U4.4 (RXD)
CAN_TX: U3.44 (PB6), U4.1 (TXD)
CUR1: R22.P$1, U7.23 (SOA)
CUR2: R23.P$1, U7.22 (SOB)
CUR3: R24.P$1, U7.21 (SOC)
DAC: DAC.P$1, R2.P$1, R3.P$2, U3.12 (PA4)
DRV8323_CS: U3.17 (PB0), U7.30 (CS)
DRV8323_MISO: R25.P$2, U3.40 (PC11), U7.27 (MISO)
DRV8323_MOSI: U3.2 (PC13), U7.28 (MOSI)
DRV8323_SCLK: U3.39 (PC10), U7.29 (SCLK)
FCUR1: C34.P$1, R22.P$2, U3.11 (PA3)
FCUR2: C35.P$1, R23.P$2, U3.14 (PA6)
FCUR3: C36.P$1, R24.P$2, U3.18 (PB1)
GHA: D5.1 (K), R28.P$1, U7.6 (GHA)
GHA_D: D5.2 (A), Q1.4 (G), R28.P$2
GHB: D8.1 (K), R30.P$1, U7.15 (GHB)
GHB_D: D8.2 (A), Q3.4 (G), R30.P$2
GHC: D11.1 (K), R32.P$1, U7.16 (GHC)
GHC_D: D11.2 (A), Q5.4 (G), R32.P$2
GLA: D3.1 (K), R27.P$1, U7.8 (GLA)
GLA_D: D3.2 (A), D4.1 (K), Q2.4 (G), R27.P$2
GLB: D6.1 (K), R29.P$1, U7.13 (GLB)
GLB_D: D6.2 (A), D7.1 (K), Q4.4 (G), R29.P$2
GLC: D9.1 (K), R31.P$1, U7.18 (GLC)
GLC_D: D9.2 (A), D10.1 (K), Q6.4 (G), R31.P$2
GND: AUX1.8, AUX2.7, AUX2H.P$6 (6), C3.P$2, C4.P$2, C5.P$2, C6.P$2, C7.P$2, C8.P$2, C9.P$2, C10.P$2, C11.P$2, C12.P$2, C13.P$1, C14.P$2, C15.P$2, C16.P$2, C17.P$2, C18.P$2, C19.P$2, C20.P$2, C21.P$2, C22.P$2, C23.P$2, C23\.P$2, C24.P$2, C25.P$2, C26.P$2, C27.P$2, C28.P$2, C29.P$2, C30.P$2, C31.P$2, C32.P$2, C33.P$2, C34.P$2, C35.P$2, C36.P$2, C42.P$1, C87.P$2, CAN1.3, CAN2.3, CAN_DBG.3, DG1.P$1, J3.6, R3.P$1, R16.P$1, R18.P$2, R19.P$2, R38.P$1, SH4.2, SWD.4, U1.7 (GND), U2.B1 (PGND), U2.B2 (AGND), U3.49 (THERMALPAD), U4.2 (GND), U4.8 (STB), U5.5 (TEST), U5.13 (GND), U7.25 (AGND), U8.6 (GND_2), U8.7 (GND)
LED1: D1.CATHODE, U3.28 (PB15)
LED2: D2.CATHODE, U3.29 (PC6)
MOTOR1: U3.8 (PA0), U7.32 (INHA)
MOTOR2: U3.9 (PA1), U7.34 (INHB)
MOTOR3: U3.10 (PA2), U7.36 (INHC)
MOTOR_ENABLE: U3.3 (PC14-OSC32_IN), U7.31 (ENABLE)
MOTOR_FAULT: R26.P$2, U3.26 (PB13), U7.26 (FAULT)
MOTOR_HIZ: U3.4 (PC15-OSC32_OUT), U7.33 (INLA), U7.35 (INLB), U7.37 (INLC)
unnamed: C1.P$1, M3.P$1, R1.P$1
unnamed: C40.P$2, U7.40 (VGLS)
unnamed: R40.P$1, U5.11 (VDD5V)
unnamed: C3.P$1, U1.3 (VCC)
unnamed: L2.2, U2.A1 (SW)
unnamed: C39.P$2, U7.1 (CPL)
unnamed: C39.P$1, U7.2 (CPH)
unnamed: C38.P$2, U7.5 (VCP)
unnamed: C41.P$2, U7.38 (DVDD)
unnamed: D1.ANODE, R20.P$2
unnamed: D2.ANODE, R21.P$2
unnamed: R38.P$2, U1.5 (MODE)
unnamed: D14.1 (K), R34.P$1
unnamed: R39.P$1, U2.B3 (SYNC/_MODE)
unnamed: D13.1 (K), R33.P$1
unnamed: D15.1 (K), R6.P$1
unnamed: D16.1 (K), R7.P$1
NRST: C9.P$1, SWD.2, U3.7 (PG10-NRST)
RS422_A: J3.2, R35.P$2, U8.12 (A)
RS422_B: J3.3, R35.P$1, U8.11 (B)
RS422_DE: U3.24 (PB11), U8.4 (DE)
RS422_RE: U3.22 (PB10), U8.3 (!RE)
RS422_Y: J3.4, R36.P$2, U8.9 (Y)
RS422_Z: J3.5, R36.P$1, U8.10 (Z)
SHA: A.1, A.2, A.3, A.4, A.5, A.6, A.7, A.8, A.9, A.10, A.11, A.12, A.13, Q1.1 (S), Q1.2 (S), Q1.3 (S), Q2.5 (D), Q2.6 (D), Q2.7 (D), Q2.8 (D), Q2.PAD (D), U7.7 (SHA)
SHB: B.1, B.2, B.3, B.4, B.5, B.6, B.7, B.8, B.9, B.10, B.11, B.12, B.13, Q3.1 (S), Q3.2 (S), Q3.3 (S), Q4.5 (D), Q4.6 (D), Q4.7 (D), Q4.8 (D), Q4.PAD (D), U7.14 (SHB)
SHC: C.1, C.2, C.3, C.4, C.5, C.6, C.7, C.8, C.9, C.10, C.11, C.12, C.13, Q5.1 (S), Q5.2 (S), Q5.3 (S), Q6.5 (D), Q6.6 (D), Q6.7 (D), Q6.8 (D), Q6.PAD (D), U7.17 (SHC)
SWCLK: SWD.5, U3.37 (PA14)
SWDIO: SWD.3, U3.36 (PA13)
SXA_N: SH1.1, U7.10 (SNA)
SXA_P: C44.P$2, Q2.1 (S), Q2.2 (S), Q2.3 (S), RA.2, U7.9 (SPA)
SXB_N: SH2.1, U7.11 (SNB)
SXB_P: C45.P$2, Q4.1 (S), Q4.2 (S), Q4.3 (S), RB.2, U7.12 (SPB)
SXC_N: SH3.1, U7.20 (SNC)
SXC_P: C46.P$2, Q6.1 (S), Q6.2 (S), Q6.3 (S), RC.2, U7.19 (SPC)
V+: C2.P$1, C37.P$1, C38.P$1, C43.P$1, C44.P$1, C45.P$1, C46.P$1, C47.P$1, C48.P$1, C49.P$1, C50.P$1, C51.P$1, C52.P$1, C53.P$1, C54.P$1, C55.P$1, C56.P$1, C57.P$1, C58.P$1, C59.P$1, C60.P$1, C61.P$1, C62.P$1, C63.P$1, C64.P$1, C65.P$1, C66.P$1, C67.P$1, C68.P$1, C69.P$1, C70.P$1, C71.P$1, C72.P$1, C73.P$1, C74.P$1, C75.P$1, C76.P$1, C77.P$1, C78.P$1, C79.P$1, C80.P$1, C81.P$1, C82.P$1, C83.P$1, C84.P$1, C85.P$1, C86.P$1, D12.C, J1.1, J2.1, Q1.5 (D), Q1.6 (D), Q1.7 (D), Q1.8 (D), Q1.PAD (D), Q3.5 (D), Q3.6 (D), Q3.7 (D), Q3.8 (D), Q3.PAD (D), Q5.5 (D), Q5.6 (D), Q5.7 (D), Q5.8 (D), Q5.PAD (D), R15.P$2, U1.1 (VIN), U1.2 (EN/UVLO), U7.3 (VM), U7.4 (VDRAIN), VP.1, VP.2, VP.3, VP.4, VP.5, VP.6, VP.7, VP.8, VP.9, VP.10, VP.11, VP.12, VP.13
V-: C1.P$2, C2.P$2, C37.P$2, C40.P$1, C41.P$1, C43.P$2, C47.P$2, C48.P$2, C49.P$2, C50.P$2, C51.P$2, C52.P$2, C53.P$2, C54.P$2, C55.P$2, C56.P$2, C57.P$2, C58.P$2, C59.P$2, C60.P$2, C61.P$2, C62.P$2, C63.P$2, C64.P$2, C65.P$2, C66.P$2, C67.P$2, C68.P$2, C69.P$2, C70.P$2, C71.P$2, C72.P$2, C73.P$2, C74.P$2, C75.P$2, C76.P$2, C77.P$2, C78.P$2, C79.P$2, C80.P$2, C81.P$2, C82.P$2, C83.P$2, C84.P$2, C85.P$2, C86.P$2, D4.2 (A), D7.2 (A), D10.2 (A), D12.A, J1.2, J2.2, R1.P$2, RA.1, RB.1, RC.1, SH1.2, SH2.2, SH3.2, SH4.1, U7.39 (GND), U7.PAD, VN.1, VN.2, VN.3, VN.4, VN.5, VN.6, VN.7, VN.8, VN.9, VN.10, VN.11, VN.12, VN.13
VBAT_SENSE: C31.P$1, R15.P$1, R16.P$2, U3.31 (PA9)
VSW: L1.2, U1.8 (LX)
VTEMP_FET: C32.P$1, R17.P$2, R18.P$1, U3.25 (PB12)
VTEMP_MOT: C33.P$1, R19.P$1, TEMP.2, U3.30 (PA8)

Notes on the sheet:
PCB rev divider HI / LO r1.1/r1.2 - open / 100k r1.3 - 100k / open



Board: 4 copper layers, 46.0 x 46.0 mm, 192 parts (117 on the bottom side), 100 nets.

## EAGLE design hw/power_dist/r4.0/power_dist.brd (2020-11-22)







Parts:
C1, C15: 1uF 100V; C0805; MPN GCM21BC72A105KE36L
C2, C6, C11, C12: 1uF; C0603; MPN MF-CAP-0603-1uF
C3, C9: 10uF 50V; C1206; MPN C3216X7R1H106K160AE
C4, C5, C7, C8, C10, C16: 0.1uF; C0603; MPN MF-CAP-0603-0.1uF
C13, C14: 0.01uF; C0603; MPN MF-CAP-0603-0.01uF
C17: DNP; C0603
CAN1, CAN2: JST-PH3SMT_VERT; JST_B3B_PH-SM4-TB(LF)(SN); MPN B3B-PH-SM4-TB(LF)(SN)
D1: SMBJ51CA-E3/52; DIODE_DO-214AC; MPN SMBJ51CA-E3/52
D2: MF-DIO-SOD123-1N4148; SOD-123
D3: FSV10150V; TO277-3L_ONS; MPN FSV10150V
D4, D5: LED_SINGLE-0603; LED0603; MPN MF-LED-0603-RED
DB_3: PAD24AWG_PAD; 24AWG_PAD
DB_G: PAD24AWG_PAD; 24AWG_PAD
DB_VIN: PAD24AWG_PAD; 24AWG_PAD
DB_VSW: PAD24AWG_PAD; 24AWG_PAD
J1: JST-ZH6SMT_VERT; JST_B6B-ZR-SM4-TF(LF)(SN); MPN B6B-ZR-SM4-TF(LF)(SN)
J2: JST-PH4SMT_VERT; JST_B4B_PH-SM4-TB(LF)(SN); MPN B4B-PH-SM4-TB(LF)(SN)
J3: JST-PH5VERT; JST_B5B_PH-SM4-TB(LF)(SN); MPN B5B-PH-SM4-TB(LF)(SN)
L1: CBC3225T330KR; IND_TAIYO_CBC3225_TAY; MPN CBC3225T330KR
P1, P2, P3, P4, P5, P6: XT30P; MPN XT30UPB-F
P7: XT90PW-M
Q1, Q2, Q3: PSMN4R8-100BSEJ; D2PAK_SOT404_NEX; MPN PSMN4R8-100BSEJ
Q4: MF-DSC-SOT233-BSS138; SOT-23-3
Q5: MF-DSC-SOT233-MMBT3906; SOT-23-3
Q6: MF-DSC-SOT233-MMBT3904; SOT-23-3
R1, R2, R3: 10k; R0603; MPN MF-RES-0603-10K
R4, R8: 140k 1%; R0603; MPN RC0603FR-07140KL
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

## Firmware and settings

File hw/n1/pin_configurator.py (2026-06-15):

#!/usr/bin/python3

# Copyright 2023 mjbots Robotic Systems, LLC.  info@mjbots.com
#
# Licensed under the Apache License, Version 2.0 (the "License");
# you may not use this file except in compliance with the License.
# You may obtain a copy of the License at
#
#     http://www.apache.org/licenses/LICENSE-2.0
#
# Unless required by applicable law or agreed to in writing, software
# distributed under the License is distributed on an "AS IS" BASIS,
# WITHOUT WARRANTIES OR CONDITIONS OF ANY KIND, either express or implied.
# See the License for the specific language governing permissions and
# limitations under the License.

import argparse
import enum
import re
import sys


class MatchStatus(enum.IntEnum):
    VALID = 1
    INCONCLUSIVE = 0
    IMPOSSIBLE = -1


def generic_search(data, to_find):
    found = [d.find(to_find) >= 0 for d in data]
    if any(found):
        return found.index(True)
    return None

def find_and_remove(data, to_find, compare=generic_search):
    hit = compare(data, to_find)
    if hit is not None:
        del(data[hit])
        return 1
    return 0


class Desired5V:
    def __init__(self, args):
        self.args = args

    def __call__(self, pins):
        for pin in pins:
            for subpin in pin.split('/'):
                if subpin.find('5V') < 0:
                    return MatchStatus.IMPOSSIBLE
        if len(pins) == self.args.pins:
            return MatchStatus.VALID
        return MatchStatus.INCONCLUSIVE


class DesiredADC:
    def __init__(self, args):
        self.args = args
        self.available_adcs = [
            x for x in ['ADC1', 'ADC2', 'ADC3', 'ADC4']
            if x not in self.args.exclude
        ]

    def all_analog(self, maybe_pair):
        pins = maybe_pair.split('/')
        return all([x.find('ANALOG') >= 0 for x in pins])

    def find_adc(self, data, to_find):
        found = [d.find(to_find) >= 0 and self.all_analog(d) for d in data]
        if any(found):
            return found.index(True)
        return None

    def __call__(self, pins):
        # This is not strictly correct, as it will count multiple
        # channels on the same pin as multiple ADCs.  We'll fix that
        # in an ad-hoc way if it matters.

        adc_present = []
        pins_copy = pins[:]
        for adc in self.available_adcs:
            adc_present.append(find_and_remove(pins_copy, adc,
                                               compare=self.find_adc))

        count = sum(adc_present)
        if count == 2:
            return MatchStatus.VALID
        elif (2 - count) + len(pins) > self.args.pins:
            return MatchStatus.IMPOSSIBLE
        else:
            return MatchStatus.INCONCLUSIVE


class DesiredUART:
    def __init__(self, args):
        self.args = args
        self.available_uarts = [
            x for x in ['USART1', 'USART2', 'USART3', 'UART4', 'UART5', 'LPUART1']
            if x not in self.args.exclude
        ]

    def __call__(self, pins):

        results = []
        for uart in self.available_uarts:
            pins_copy = pins[:]
            tx = find_and_remove(pins_copy, f'{uart}_TX')
            rx = find_and_remove(pins_copy, f'{uart}_RX')

            if tx > 0 and rx > 0:
                return MatchStatus.VALID
            elif (2 - tx - rx) + len(pins) > self.args.pins:
                results.append(MatchStatus.IMPOSSIBLE)
            else:
                results.append(MatchStatus.INCONCLUSIVE)
        return max(results)


class DesiredI2C:
    def __init__(self, args):
        self.args = args
        self.available_i2c = [
            x for x in ['I2C1', 'I2C2', 'I2C3', 'I2C4', 'I2C5']
            if x not in self.args.exclude
        ]

    def __call__(self, pins):
        results = []
        for i2c in self.available_i2c:
            pins_copy = pins[:]
            sda = find_and_remove(pins_copy, f'{i2c}_SDA')
            scl = find_and_remove(pins_copy, f'{i2c}_SCL')

            if sda > 0 and scl > 0:
                return MatchStatus.VALID
            elif (2 - sda - scl) + len(pins) > self.args.pins:
                results.append(MatchStatus.IMPOSSIBLE)
            else:
                results.append(MatchStatus.INCONCLUSIVE)

        return max(results)


class DesiredQuadrature:
    def __init__(self, args):
        self.args = args
        self.available_timers = [
            x for x in ['TIM1', 'TIM2', 'TIM3', 'TIM4', 'TIM5', 'TIM8', 'TIM20']
            if x not in self.args.exclude
        ]

    def __call__(self, pins):
        results = []

        for timer in self.available_timers:
            pins_copy = pins[:]
            ch1 = find_and_remove(pins_copy, f'{timer}_CH1')
            ch2 = find_and_remove(pins_copy, f'{timer}_CH2')

            if ch1 > 0 and ch2 > 0:
                return MatchStatus.VALID
            elif (2 - ch1 - ch1) + len(pins) > self.args.pins:
                results.append(MatchStatus.IMPOSSIBLE)
            else:
                results.append(MatchStatus.INCONCLUSIVE)
        return max(results)


class DesiredSpi:
    def __init__(self, args):
        self.args = args
        self.available_spi = [
            x for x in ['SPI1', 'SPI2', 'SPI3', 'SPI4', 'SPI5']
            if x not in self.args.exclude
        ]

    def any_non_five_volt(self, pins_copy):
        for pin_pair in pins_copy:
            for pin in pin_pair.split('/'):
                if pin.find('5V') < 0:
                    return True
        return False

    def __call__(self, pins):
        results = []

        # Just check all 5 SPI types.
        for spi in self.available_spi:
            sck = 0
            miso = 0
            mosi = 0

            pins_copy = pins[:]

            sck = find_and_remove(pins_copy, f'{spi}_SCK')
            miso = find_and_remove(pins_copy, f'{spi}_MISO')
            mosi = find_and_remove(pins_copy, f'{spi}_MOSI')

            if self.args.nonspi_five_volt:
                # All remaining pins must be 5V.
                if self.any_non_five_volt(pins_copy):
                    results.append(MatchStatus.IMPOSSIBLE)
                    continue


            if sck > 0 and miso > 0 and mosi > 0:
                return MatchStatus.VALID
            elif (3 - sck - miso - mosi) + len(pins) > self.args.pins:
                results.append(MatchStatus.IMPOSSIBLE)
            else:
                results.append(MatchStatus.INCONCLUSIVE)
        return max(results)

    def find_nonspi(self, pins):
        results = []

        # Just check all 5 SPI types.
        for spi in self.available_spi:
            sck = 0
            miso = 0
            mosi = 0

            pins_copy = pins[:]

            sck = find_and_remove(pins_copy, f'{spi}_SCK')
            miso = find_and_remove(pins_copy, f'{spi}_MISO')
            mosi = find_and_remove(pins_copy, f'{spi}_MOSI')

            if sck > 0 and miso > 0 and mosi > 0:
                return pins_copy
        return None


def main():
    parser = argparse.ArgumentParser()
    parser.add_argument('--pins', type=int, default=5)
    parser.add_argument('--pinout', default='pinout.txt')
    parser.add_argument('--five-volt', action='store_true')
    parser.add_argument('--verbose', '-v', action='store_true')
    parser.add_argument('--exclude', '-e', action='append', default=[])
    parser.add_argument('--nonspi-five-volt', action='store_true')
    parser.add_argument('--max-doubled', default=10, type=int)

    parser.add_argument('--action', '-a', default='search', type=str)

    parser.add_argument('--verify', '-f', type=str)

    args = parser.parse_args()

    lines = [x.strip() for x in open(args.pinout).readlines()
             if (not x.startswith('#') and
                 x.split(' ')[0] not in args.exclude)]

    if args.action == 'search':
        do_search(args, lines)
    if args.action == 'verify':
        do_verify(args, lines)

def do_verify(args, lines):
    def get_pin(pin):
        return [x for x in lines if x.startswith(pin + ' ')][0]

    pins = []
    pin_pairs = args.verify.split(',')
    for pair in pin_pairs:
        pins.append(' / '.join([get_pin(pin) for pin in pair.split('/')]))

    to_check = [
        ('SPI', DesiredSpi(args)),
        ('QUAD', DesiredQuadrature(args)),
        ('I2C', DesiredI2C(args)),
        ('UART', DesiredUART(args)),
        ('ADC', DesiredADC(args)),
    ]

    for check in to_check:
        print(f"{check[0]} - {check[1](pins)}")

    desired_spi = DesiredSpi(args)
    nonspi_desired = [
        DesiredQuadrature(args),
        DesiredI2C(args),
        DesiredUART(args),
        DesiredADC(args),
    ]

    nonspi_pins = desired_spi.find_nonspi(pins)
    bonus = [d(nonspi_pins)
             for d in nonspi_desired].count(MatchStatus.VALID) * 2

    print(f"bonus {bonus}")



def do_search(args, lines):
    desired_spi = DesiredSpi(args)

    nonspi_desired = [
        DesiredQuadrature(args),
        DesiredI2C(args),
        DesiredUART(args),
        DesiredADC(args),
    ]

    desired = [ desired_spi ] + nonspi_desired

    if args.five_volt:
        desired.append(Desired5V(args))

    current = [0]
    tries = 0

    best_score = 1000
    best_doubled = 1000

    while True:
        tries += 1
        these_pins_doubled = [lines[x] for x in current]
        short_doubled = [x.split(' ')[0] for x in these_pins_doubled]
        these_pins = []
        while len(these_pins_doubled):
            maybe_pair = these_pins_doubled[0:2]

            if len(maybe_pair) == 1 or maybe_pair[0] == maybe_pair[1]:
                these_pins.append(maybe_pair[0])
            else:
                these_pins.append(' / '.join(maybe_pair))
            del(these_pins_doubled[0:2])

        #print(f"TRYING: {these_pins}")
        these_pins_short = []
        while len(short_doubled):
            short_pair = short_doubled[0:2]
            if len(short_pair) == 2 and short_pair[0] == short_pair[1]:
                del(short_pair[1])
            these_pins_short.append('/'.join(short_pair))
            del(short_doubled[0:2])

        doubled = ','.join(these_pins_short).count('/')

        print(f"{tries}   {','.join(these_pins_short)}     ",
              end='\n' if args.verbose else '\r')

        if tries == 116803:
            a = 1

        if doubled <= args.max_doubled:
            results = [d(these_pins) for d in desired]
        else:
            results = [MatchStatus.IMPOSSIBLE]

        b = 1

        if all([x == MatchStatus.VALID for x in results]):
            pin_count = len(current)
            nonspi_pins = desired_spi.find_nonspi(these_pins)
            bonus = [d(nonspi_pins)
                     for d in nonspi_desired].count(MatchStatus.VALID) * 2
            score = pin_count + doubled * 2 - bonus
            if doubled < best_doubled:
                best_doubled = doubled
            if score <= best_score:
                best_score = score
                print()
                print()
                print(f"FOUND after {tries} tries w/ {pin_count} pins {doubled} doubled {score} score - {bonus} bonus")
                print('\n'.join(these_pins))
                print()

        if (any([x == MatchStatus.IMPOSSIBLE for x in results]) or
              len(current) >= args.pins * 2 or
              (current[-1] + 1) >= len(lines)):
            # We need to advance the current index.  If that exceeds
            # our limit, then backtrack if possible.
            while True:
                current[-1] += 1
                if len(current) >=2 and current[-1] == current[-2]:
                    continue
                if current[-1] < len(lines):
                    break
                current.pop()
                if len(current) == 0:
                    print("IMPOSSIBLE")
                    sys.exit(1)
        else:
            if len(current) % 2 == 0:
                current.append(current[-2] + 1)
            else:
                current.append(current[-1])



if __name__ == '__main__':
    main()

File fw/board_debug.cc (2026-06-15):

// Copyright 2023 mjbots Robotic Systems, LLC.  info@mjbots.com
//
// Licensed under the Apache License, Version 2.0 (the "License");
// you may not use this file except in compliance with the License.
// You may obtain a copy of the License at
//
//     http://www.apache.org/licenses/LICENSE-2.0
//
// Unless required by applicable law or agreed to in writing, software
// distributed under the License is distributed on an "AS IS" BASIS,
// WITHOUT WARRANTIES OR CONDITIONS OF ANY KIND, either express or implied.
// See the License for the specific language governing permissions and
// limitations under the License.

#include "fw/board_debug.h"

#include <cctype>
#include <cstdlib>
#include <functional>
#include <numeric>

#include "mbed.h"

#include "mjlib/base/inplace_function.h"
#include "mjlib/base/tokenizer.h"
#include "mjlib/base/visitor.h"

#include "fw/as5047.h"
#include "fw/bldc_servo.h"
#include "fw/bootloader.h"
#include "fw/drv8323.h"
#include "fw/moteus_hw.h"
#include "fw/strtof.h"

namespace base = mjlib::base;
namespace micro = mjlib::micro;
namespace multiplex = mjlib::multiplex;

namespace moteus {
constexpr float kCalibrationStep = 0.002;
constexpr float kMaxCalPoleCount = 50.0f;

namespace {
void recurse(int count, base::inplace_function<void(int)> callback) {
  callback(count - 1);
}

bool ParseOptions(BldcServo::CommandData* command, base::Tokenizer* tokenizer,
                  const char* valid_options) {
  while (tokenizer->remaining().size()) {
    const auto token = tokenizer->next();
    // We accept optional arguments, each prefixed by a single
    // character.
    if (token.size() < 1) { continue; }
    const char option = token[0];
    if (::strchr(valid_options, option) == nullptr) {
      return false;
    }

    const auto maybe_value = Strtof(&token[1]);
    if (!maybe_value) {
      return false;
    }
    const auto value = *maybe_value;
    switch (option) {
      case 'p': {
        command->kp_scale = value;
        break;
      }
      case 'd': {
        command->kd_scale = value;
        break;
      }
      case 'i': {
        command->ilimit_scale = value;
        break;
      }
      case 's': {
        command->stop_position = value;
        break;
      }
      case 'f': {
        command->feedforward_Nm = value;
        break;
      }
      case 't': {
        command->timeout_s = value;
        break;
      }
      case 'a': {
        command->accel_limit = value;
        break;
      }
      case 'v': {
        command->velocity_limit = value;
        break;
      }
      case 'o': {
        command->fixed_voltage_override = value;
        break;
      }
      case 'c': {
        command->fixed_current_override = value;
        break;
      }
      case 'b': {
        command->ignore_position_bounds = value != 0.0f;
        break;
      }
      case 'q': {
        command->meas_ind_axis = static_cast<int8_t>(value);
        break;
      }
      default: {
        return false;
      }
    }
  }
  return true;
}
}

class BoardDebug::Impl {
 public:
  struct HistogramSource;

  Impl(micro::Pool* pool,
       micro::CommandManager* command_manager,
       micro::TelemetryManager* telemetry_manager,
       multiplex::MicroServer* multiplex_protocol,
       BldcServo* bldc_servo)
      : multiplex_protocol_(multiplex_protocol),
        bldc_(bldc_servo) {
    command_manager->Register(
        "d", std::bind(&Impl::HandleCommand, this,
                       std::placeholders::_1, std::placeholders::_2));

    data_update_ = telemetry_manager->Register("board_debug", &data_);
  }

  void PollMillisecond() {
    if (motor_cal_mode_ != kNoMotorCal) {
      DoCalibration();
    }
    if (histogram_active_) {
      DoHistogram();
    }
  }

  bool ParseHistogramChannel(HistogramSource* source, const std::string_view& spec) {
    // The format of this specification is a single character source:
    //
    //  t - electrical theta
    //  c - compensated
    //  f - filtered
    //  o - offset
    //  r - raw
    //  v - pll output velocity
    //  ... etc ...
    //
    // followed by an optional single digit to specify the encoder
    // channel, and then an optional list of non-digit flags:
    //
    //  d - derivative

    source->derivative = false;
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

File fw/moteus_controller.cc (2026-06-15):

// Copyright 2023 mjbots Robotic Systems, LLC.  info@mjbots.com
//
// Licensed under the Apache License, Version 2.0 (the "License");
// you may not use this file except in compliance with the License.
// You may obtain a copy of the License at
//
//     http://www.apache.org/licenses/LICENSE-2.0
//
// Unless required by applicable law or agreed to in writing, software
// distributed under the License is distributed on an "AS IS" BASIS,
// WITHOUT WARRANTIES OR CONDITIONS OF ANY KIND, either express or implied.
// See the License for the specific language governing permissions and
// limitations under the License.

#include "fw/moteus_controller.h"

#include "mjlib/base/limit.h"

#include "fw/aux_port.h"
#include "fw/drv8323.h"
#include "fw/math.h"
#include "fw/moteus_hw.h"
#include "fw/motor_position.h"
#include "fw/multi_transport_datagram_server.h"
#include "fw/uart_fdcanusb_micro_server.h"

namespace micro = mjlib::micro;
namespace multiplex = mjlib::multiplex;
using mjlib::base::Limit;

namespace moteus {

using Value = multiplex::MicroServer::Value;

namespace {

// Version 3: The enumerated values for the control mode changed
// meaning and voltage scale changed.
//
// Version 4: The scaling factors associated with velocity and
// position changed.
//
// Version 5: The "rezero state" was renamed to "home state" and the
// enumeration has new meaning.

constexpr int kRegisterMapVersion = 5;

template <typename T>
Value IntMapping(T value, size_t type) {
  switch (type) {
    case 0: return static_cast<int8_t>(value);
    case 1: return static_cast<int16_t>(value);
    case 2: return static_cast<int32_t>(value);
    case 3: return static_cast<float>(value);
  }
  MJ_ASSERT(false);
  return static_cast<int8_t>(0);
}

template <typename T>
Value ScaleSaturate(float value, float scale) {
  if (!std::isfinite(value)) {
    return std::numeric_limits<T>::min();
  }

  const float scaled = value / scale;
  const auto max = std::numeric_limits<T>::max();
  const auto float_max = static_cast<float>(max);

  // We purposefully limit to +- max, rather than to min.  The minimum
  // value for our two's complement types is reserved for NaN.
  return static_cast<T>(Limit<float>(scaled, -float_max, float_max));
}

Value ScaleMapping(float value,
                   float int8_scale, float int16_scale, float int32_scale,
                   size_t type) {
  switch (type) {
    case 0: return ScaleSaturate<int8_t>(value, int8_scale);
    case 1: return ScaleSaturate<int16_t>(value, int16_scale);
    case 2: return ScaleSaturate<int32_t>(value, int32_scale);
    case 3: return Value(value);
  }
  MJ_ASSERT(false);
  return Value(static_cast<int8_t>(0));
}

Value ScalePosition(float value, size_t type) {
  return ScaleMapping(value, 0.01f, 0.0001f, 0.00001f, type);
}

Value ScaleVelocity(float value, size_t type) {
  return ScaleMapping(value, 0.1f, 0.00025f, 0.00001f, type);
}

Value ScaleAcceleration(float value, size_t type) {
  return ScaleMapping(value, 0.05f, 0.001f, 0.00001f, type);
}

Value ScaleTemperature(float value, size_t type) {
  return ScaleMapping(value, 1.0f, 0.1f, 0.001f, type);
}

Value ScalePwm(float value, size_t type) {
  return ScaleMapping(value, 1.0f / 127.0f, 1.0f / 32767.0f,
                      1.0f / 2147483647.0f,
                      type);
}

Value ScaleCurrent(float value, size_t type) {
  // For now, current and temperature have identical scaling.
  return ScaleTemperature(value, type);
}

Value ScaleVoltage(float value, size_t type) {
  return ScaleMapping(value, 0.5f, 0.1f, 0.001f, type);
}

Value ScaleTorque(float value, size_t type) {
  return ScaleMapping(value, 0.5f, 0.01f, 0.001f, type);
}

Value ScaleTime(float value, size_t type) {
  return ScaleMapping(value, 0.01f, 0.001f, 0.000001f, type);
}

Value ScalePower(float value, size_t type) {
  return ScaleMapping(value, 10.0f, 0.05f, 0.0001f, type);
}

int8_t ReadIntMapping(Value value) {
  return std::visit([](auto a) {
    return static_cast<int8_t>(a);
  }, value);
}

int32_t ReadInt32Mapping(Value value) {
  return std::visit([](auto a) {
    return static_cast<int32_t>(a);
  }, value);
}

struct ValueScaler {
  float int8_scale;
  float int16_scale;
  float int32_scale;

  float operator()(int8_t value) const {
    if (value == std::numeric_limits<int8_t>::min()) {
      return std::numeric_limits<float>::quiet_NaN();
    }
    return value * int8_scale;
  }

  float operator()(int16_t value) const {
    if (value == std::numeric_limits<int16_t>::min()) {
      return std::numeric_limits<float>::quiet_NaN();
    }
    return value * int16_scale;
  }

  float operator()(int32_t value) const {
    if (value == std::numeric_limits<int32_t>::min()) {
      return std::numeric_limits<float>::quiet_NaN();
    }
    return value * int32_scale;
  }

  float operator()(float value) const {
    return value;
  }
};

float ReadScaleMapping(Value value,
                       float int8_scale,
                       float int16_scale,
                       float int32_scale) {
  return std::visit(ValueScaler{int8_scale, int16_scale, int32_scale}, value);
}

float ReadPwm(Value value) {
  return ReadScaleMapping(value, 1.0f / 127.0f, 1.0f / 32767.0f,
                          1.0f / 2147483647.0f);
}

float ReadVoltage(Value value) {
  return ReadScaleMapping(value, 0.5f, 0.1f, 0.001f);
}

float ReadPosition(Value value) {
  return ReadScaleMapping(value, 0.01f, 0.0001f, 0.00001f);
}

float ReadVelocity(Value value) {
  return ReadScaleMapping(value, 0.1f, 0.00025f, 0.00001f);
}

float ReadAcceleration(Value value) {
  return ReadScaleMapping(value, 0.05f, 0.001f, 0.00001f);
}

float ReadCurrent(Value value) {
  return ReadScaleMapping(value, 1.0f, 0.1f, 0.001f);
}

float ReadTorque(Value value) {
  return ReadScaleMapping(value, 0.5f, 0.01f, 0.001f);
}

float ReadTime(Value value) {
  return ReadScaleMapping(value, 0.01f, 0.001f, 0.000001f);
}

template <typename T, size_t N>
int8_t PinsToBits(const std::array<T, N>& array) {
  static_assert(N <= 7);
  int8_t result = 0;
  for (size_t i = 0; i < array.size(); i++) {
    result |= (array[i] ? 1 : 0) << i;
  }
  return result;
}
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

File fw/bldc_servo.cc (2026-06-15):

// Copyright 2023 mjbots Robotic Systems, LLC.  info@mjbots.com
//
// Licensed under the Apache License, Version 2.0 (the "License");
// you may not use this file except in compliance with the License.
// You may obtain a copy of the License at
//
//     http://www.apache.org/licenses/LICENSE-2.0
//
// Unless required by applicable law or agreed to in writing, software
// distributed under the License is distributed on an "AS IS" BASIS,
// WITHOUT WARRANTIES OR CONDITIONS OF ANY KIND, either express or implied.
// See the License for the specific language governing permissions and
// limitations under the License.

#include "bldc_servo.h"

#include <algorithm>
#include <atomic>
#include <cmath>
#include <functional>

#include "mbed.h"

#include "PeripheralPins.h"

#include "mjlib/base/assert.h"
#include "mjlib/base/windowed_average.h"

#include "fw/bldc_servo_control.h"
#include "fw/bldc_servo_position.h"
#include "fw/foc.h"
#include "fw/moteus_hw.h"
#include "fw/stm32_dma.h"
#include "fw/stm32g4_adc.h"
#include "fw/thermistor.h"
#include "fw/torque_model.h"

#ifdef wait_us
#undef wait_us
#endif

namespace micro = mjlib::micro;

namespace moteus {

namespace {

RateConfig MakeRateConfig(int pwm_rate_hz_in, float current_sample_time) {
  const int board_min_pwm_rate_hz =
      (g_measured_hw_family == 0 &&
       g_measured_hw_rev == 2) ? 60000 :
      15000;
  return RateConfig(pwm_rate_hz_in, board_min_pwm_rate_hz,
                    current_sample_time);
}

constexpr int kCalibrateCount = 256;

constexpr int kMaxVelocityFilter = 256;

IRQn_Type FindUpdateIrq(TIM_TypeDef* timer) {
#if defined(TARGET_STM32G4)
  if (timer == TIM1) {
    return TIM1_UP_TIM16_IRQn;
  } else if (timer == TIM2) {
    return TIM2_IRQn;
  } else if (timer == TIM3) {
    return TIM3_IRQn;
  } else if (timer == TIM4) {
    return TIM4_IRQn;
  } else if (timer == TIM5) {
    return TIM5_IRQn;
  }
  MJ_ASSERT(false);
  return TIM2_IRQn;
#else
#error "Unknown target"
#endif
}

volatile uint32_t* FindCcr(TIM_TypeDef* timer, PinName pin) {
  const auto function = pinmap_function(pin, PinMap_PWM);

  const auto inverted = STM_PIN_INVERTED(function);
  MJ_ASSERT(!inverted);

  const auto channel = STM_PIN_CHANNEL(function);

  switch (channel) {
    case 1: { return &timer->CCR1; }
    case 2: { return &timer->CCR2; }
    case 3: { return &timer->CCR3; }
    case 4: { return &timer->CCR4; }
  }
  MJ_ASSERT(false);
  return nullptr;
}

uint32_t FindSqr(PinName pin) {
  const auto function = pinmap_function(pin, PinMap_ADC);

  const auto channel = STM_PIN_CHANNEL(function);
  return channel;
}

/// Read a digital input, but without configuring it in any way.
class PhaseMonitors {
 public:
  PhaseMonitors(PinName pin1, PinName pin2, PinName pin3) {
    const uint32_t port_index1 = STM_PORT(pin1);
    const uint32_t port_index2 = STM_PORT(pin3);
    const uint32_t port_index3 = STM_PORT(pin3);
    MJ_ASSERT(port_index1 == port_index2);
    MJ_ASSERT(port_index2 == port_index3);

    GPIO_TypeDef* gpio = reinterpret_cast<GPIO_TypeDef*>([&]() {
      switch (port_index1) {
        case PortA: return GPIOA_BASE;
        case PortB: return GPIOB_BASE;
        case PortC: return GPIOC_BASE;
        case PortD: return GPIOD_BASE;
        case PortE: return GPIOE_BASE;
        case PortF: return GPIOF_BASE;
      }
      MJ_ASSERT(false);
      return GPIOA_BASE;
      }());
    reg_in_ = &gpio->IDR;
    mask_ = static_cast<uint32_t>(1 << (static_cast<uint32_t>(pin1) & 0xf)) |
        static_cast<uint32_t>(1 << (static_cast<uint32_t>(pin2) & 0xf)) |
        static_cast<uint32_t>(1 << (static_cast<uint32_t>(pin3) & 0xf));
  }

  bool read() {
    return (*reg_in_ & mask_) != 0;
  }

 private:
  volatile uint32_t* reg_in_ = nullptr;
  uint32_t mask_ = 0;
};

}

class BldcServo::Impl : public BldcServoControl<BldcServo::Impl> {
 public:
  Impl(micro::PersistentConfig* persistent_config,
       micro::TelemetryManager* telemetry_manager,
       MillisecondTimer* millisecond_timer,
       MotorDriver* motor_driver,
       AuxADC* aux_adc,
       AuxPort* aux1_port,
       AuxPort* aux2_port,
       MotorPosition* motor_position,
       const Options& options)
      : options_(options),
        ms_timer_(millisecond_timer),
        motor_driver_(motor_driver),
        aux_adc_(aux_adc),
        aux1_port_(aux1_port),
        aux2_port_(aux2_port),
        motor_position_(motor_position),
        pwm1_(options.pwm1),
        pwm2_(options.pwm2),
        pwm3_(options.pwm3),
        phase_monitors_(options.pwm1, options.pwm2, options.pwm3),
        current1_(options.current1),
        current2_(options.current2),
        current3_(options.current3),
        vsense_(options.vsense),
        vsense_sqr_(FindSqr(options.vsense)),
        tsense_(options.tsense),
        tsense_sqr_(FindSqr(options.tsense)),
        msense_(options.msense),
        msense_sqr_(FindSqr(options.msense)),
        debug_dac_(options.debug_dac),
#ifdef MOTEUS_DEBUG_OUT
        debug_out_(options.debug_out),
#endif
        vsense_adc_scale_(g_hw_pins.vsense_adc_scale) {

    persistent_config->Register("servo", &config_,
                                std::bind(&Impl::UpdateConfig, this));
    persistent_config->Register("servopos", &position_config_,
                                std::bind(&Impl::UpdateConfig, this));
    telemetry_manager->Register("servo_stats", &status_);
    telemetry_manager->Register("servo_cmd", &telemetry_data_);
    telemetry_manager->Register("servo_control", &control_);

    // The motor driver's csa_settling_time() depends on its
    // csa_gain config, which is registered separately as
    // "drv8323_conf".  Have the driver re-trigger UpdateConfig
    // whenever its config changes so rate_config_'s min_pwm /
    // max_pwm track csa_gain live.
    motor_driver_->SetConfigUpdateCallback(
        std::bind(&Impl::UpdateConfig, this));

    UpdateConfig();

    MJ_ASSERT(!g_impl_);
    g_impl_ = this;
  }

  void Start() {
    ConfigureADC();
    ConfigureLPTIM1();
    ConfigureDmaLptimTrigger();
    ConfigurePwmIrq();

    if (options_.debug_uart_out != NC) {
      const auto uart = pinmap_peripheral(
          options_.debug_uart_out, PinMap_UART_TX);
      debug_uart_ = onboard_debug_uart_ =
          reinterpret_cast<USART_TypeDef*>(uart);
    }
  }

  ~Impl() {
    g_impl_ = nullptr;
  }

  void Command(const CommandData& data) {
    if (data.mode == kFault ||
        data.mode == kEnabling ||
        data.mode == kCalibrating ||
        data.mode == kCalibrationComplete) {
      // These are not valid states to command.  Ignore the command
      // entirely.
      return;
    }

    // Actually setting values will happen in the interrupt routine,
    // so we need to update this atomically.
    CommandData* next = next_data_;
    *next = data;

    // Apply defaults, transform positions, and validate the command.
    errc err = PrepareCommand(next);

    telemetry_data_ = *next;
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

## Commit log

2020-08-14 Switch to PySide2 for better compatibility with ubuntu 20.04
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2020-08-15 Implement beginnings of static torque ripple test cycle
2020-08-15 Draft of a script to process static torque ripple results
2020-08-15 Improve static torque ripple test cycle
    * Test with "d stop"
    * Test with torque in both directions
    * Actually handle parsing errors from transducer
    [dynamometer_drive.cc]
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2020-08-16 dynamometer_drive: Print regular status and update mjlib
    This mjlib should hopefully hang/segfault less since it fixes at least
    some race conditions with canceling fdcanusb_frame streams.
    [dynamometer_drive.cc]
2020-08-17 Slightly tweak up the minimum sample time after some trial and error experimentation
    [bldc_servo.cc]
2020-08-17 Add a test cycle for verifying the pwm cycle overrun value
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2020-08-18 moteus_tool: Calibration improvements
    * Actually pass the calibration speed to the correct 'd' command
    * Optionally emit the entirety of the calibration dataset to a file
    * --verbose should write all emissions, not just ack'd ones
2020-08-18 Make moteus_tool calibration not barf on possible new fields
    The board may in the future emit additional data per line. Now,
    moteus_tool won't die if sees extra things, it will just ignore them.
2020-08-18 Report more information during the calibration cycle
    Now when calibrating, we report at 100Hz instead of 50Hz, and we
    report the 3 phase currents at each time step in addition to the
    commanded phase and encoder reading. This should be enough
    information to calibrate anti-cogging in addition to the DQ transform.
2020-08-18 A script to plot phase currents from a version '2' calibration
2020-08-18 Increase the ADC prescaler to 4x
    Now that I plotted all 3 phase currents during a calibration cycle, it
    was obvious the ADCs weren't working correctly. The sample time was
    not the problem after all, but the prescaler was. Increase the
    prescaler, drop the sample time, and now the current waveforms are
    nice and smooth across all three phases.
    [bldc_servo.cc]
2020-08-18 Factor out file parsing so it can be unit tested
    Also, parse the new current information
2020-08-22 The "motor-not-configured" fault should trip in vdq mode too
2020-08-22 Config for 4114 motor
    [20200819-devkit-4114.cfg]
2020-08-22 I found a board for which a 6x ADC prescaler was needed... sigh
2020-08-22 Discard the very first calibration entry
    Experimentation has shown it to be largely bogus
2020-08-22 Add a way to flip signs when analyzing torque ripple tests
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2020-08-23 Provide an option to change the sign of the torque transducer
2020-08-23 Refactor moteus_tool to keep device state in one place
2020-08-23 Switch moteus_tool to get structured data via the binary interface
2020-09-01 Rev the upper and lower leg for additional strength
    [20200417-upper_leg.3mf, 20200708-lower_leg_and_bracket.3mf, 20200825-lower_leg_and_bracket.3mf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]
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2020-09-02 Switch the default cpu back to k8 to match the devkit video
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2020-09-03 Initial bit of position mode validation
    This also adds a d term to the "rigid" mode for the fixture, which has
    been tested across all the things which use it.
    [dynamometer_drive.cc]
2020-09-07 More passes at lower leg
    [3x_foot_bracket.3mf, foot_bracket.stl, lower_leg.stl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]
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2020-09-10 Actually fail when the dynanometer_drive tool fails
    [firmware_validate.py]
2020-09-10 Add a test cycle to verify low speed position mode control
    The performance here isn't great, so the initial tolerances are wide,
    and we don't even try to do it from non-zero start positions.
    [dynamometer_drive.cc, firmware_validate.py]
2020-09-11 Actually stop the two devices if we have exceptions from any context
2020-09-11 Slightly expand some test tolerances
    [dynamometer_drive.cc]
2020-09-11 Track control position as an int64 with more precision
    Previously, control_position was a float measured in post-gearbox
    terms. This had a number of problems, the biggest was that velocity
    control was problematic as you got more than a revolution or two away
    from 0. Since the internal control loop needs to advance the control
    position every 1/40000s, floats did not have enough resolution to
    actually cause things to advance with any precision.
    Now, the control_position is measured in terms of 1/65536 of the
    pre-gearbox integer position. This allows accurate velocity control
    down to at least 0.0001 rev/s pre-gearbox uniformly across the entire
    range of operation. Also, the control loop is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
    [bldc_servo.cc, dynamometer_drive.cc, firmware_validate.py]
2020-09-11 Implement a "stay within bounds" mode
    This creates a new control mode that operates to control 0 torque
    (modulo feedforward) when the position is between two bounds. Outside
    of that region, the normal PID controller is used to force the
    position back to one of the bounds.
    One or both (not sure why) of the bounds can be nan to create
    one-sided regions. A feedforward torque can also be used which will
    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
2020-09-12 Initial work on r4.5
    [controller.brd, controller.sch]
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2020-09-12 Improve default drive strength and timing
    This gives better power efficiency and performance across the rated
    input voltage range.
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2020-09-14 Fix ADC configuration problems.
    * We were accidentally configuring ADC4/5 to sample two consecutive
    channels when we wanted to just do one.
    * Ensure that all of the channels are set in single mode, not
    continuous.
    * We don't need to manually clear EOC, it will be cleared as soon as
    DR is read.
    * Now that we aren't reading two things, we no longer need to manually
    stop the ADCs.
    * We also don't need to "flush" anything out of the system.
    [bldc_servo.cc]
2020-09-14 Do our PWM overrun check after sampling is complete
    Previously we were waiting for the entire ADC conversion to complete
    which was overly conservative. This lets us get about a 20% higher
    maximum voltage out.
2020-09-16 Add test through holes for the CAN bus on a 2mm spacing
    [controller.brd]
2020-09-21 r4.5 as sent to MF
    [controller.brd, controller.sch]
2020-10-01 Add a solid model for the power dist board
    [power_dist_r3_1.step]
2020-10-01 The qdd100 had a reducer
    [20200807-qdd100.cfg]
2020-10-01 Random 3d prints
    [knee_conduit.3mf, knee_conduit_capture.stl, knee_conduit_top.stl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]
2020-10-08 More 3d prints
    [20200223-upper_motor_joint.3mf, 20201008-shoulder_conduit.3mf, 20201008-upper_motor_joint.3mf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]
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2020-10-22 Implement a cooldown period when removing power
    This leaves the motor in a "brake" configuration for a fixed number of
    cycles before disabling the motor driver. It is intended to reduce DC
    bus transients when stopping from high current.
    If the DRV8323 experiences an over-current fault, it internally uses a
    different mechanism to mitigate this by overriding the drive strength
    to a low value. We can't do that on the fly easily, so do this
    instead.
    [bldc_servo.cc]
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2020-10-28 Switch to use the native.existing_rule pattern
    This makes our diamond dependency handling more robust, as
    dependencies don't have to be manually excluded in a hard to determine
    way depending upon the entire transitive closure.
2020-10-29 Add a .step file for the qdd100
    [20201029-qdd100-beta-mechanical.step]
2020-10-29 Tweak lower leg to be in PC with variable infill
    [lower_leg_and_bracket.3mf]
2020-11-11 Make sure that qdd100s have the proper max current limit
    [20200807-qdd100.cfg]
2020-11-11 The power_dist board doesn't sleep
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2020-11-20 WIP of power_dist r4
    [LM5066I_Design_Calculator_REV_C.XLSX, power_dist.brd, power_dist.sch]
2020-11-20 power_dist r4 rough layout and most things renumbered
    [LM5066I_Design_Calculator_REV_C.XLSX, power_dist.brd, power_dist.sch]
2020-11-21 WIP checkpoint of power_dist r4
    [power_dist.brd, power_dist.sch]
2020-11-21 power_dist r4: Checkpoint, most power/gnd routed
    [LM5066I_Design_Calculator_REV_C.XLSX, power_dist.brd, power_dist.sch]
2020-11-21 power_dist r4: Resize and rough place silks
    [power_dist.brd, power_dist.sch]
2020-11-21 power_dist r4: Place logo
    [power_dist.brd]
2020-11-21 power_dist r4: Routed and labels
    [power_dist.brd, power_dist.sch]
2020-11-21 power_dist r4: Optionally ground one of the mounting holes
    [power_dist.brd, power_dist.sch]
2020-11-21 power_dist r4: Assign part numbers
    [power_dist.brd, power_dist.sch]
2020-11-21 power_dist r4: Update XT90 silk to be closer to actual part
    [power_dist.brd, power_dist.sch]
2020-11-21 power_dist r4: Update to 6mm spacing
    [power_dist.brd]
2020-11-21 power_dist r4: Pass ERC
    [power_dist.sch]
2020-11-22 power_dist: Use VSAMP_OUT to monitor the pre-charge cycle
    This will fault if the pre-charge cycle fails. It also only works on
    boards that have been reworked to have the correct voltage sampling
    resistors installed. (r3.1 boards shipped prior to 2020-11-22 have
    incorrect sampling resistors installed).
2020-11-22 power_dist r4: Add some DNP resistors for PGD and FB
    [power_dist.brd, power_dist.sch]
2020-11-22 power_dist r4: Fix silk placement
    [power_dist.brd]
2020-11-25 Snapshot of r4.0
    [power_dist.brd, power_dist.sch]

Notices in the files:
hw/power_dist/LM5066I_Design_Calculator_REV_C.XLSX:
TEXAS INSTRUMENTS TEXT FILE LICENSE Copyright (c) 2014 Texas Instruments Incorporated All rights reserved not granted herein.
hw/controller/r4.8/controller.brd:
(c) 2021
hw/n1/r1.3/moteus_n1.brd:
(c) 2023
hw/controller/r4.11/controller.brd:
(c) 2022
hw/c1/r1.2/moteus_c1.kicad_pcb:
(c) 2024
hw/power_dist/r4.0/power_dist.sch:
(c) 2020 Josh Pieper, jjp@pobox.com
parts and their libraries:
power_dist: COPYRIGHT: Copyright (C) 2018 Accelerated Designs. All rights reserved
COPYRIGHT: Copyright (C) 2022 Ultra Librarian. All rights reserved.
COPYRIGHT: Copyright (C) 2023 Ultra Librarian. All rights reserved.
